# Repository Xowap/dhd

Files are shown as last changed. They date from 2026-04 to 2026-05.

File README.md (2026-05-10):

# DHD — Dial Hifi Device

<p align="center">
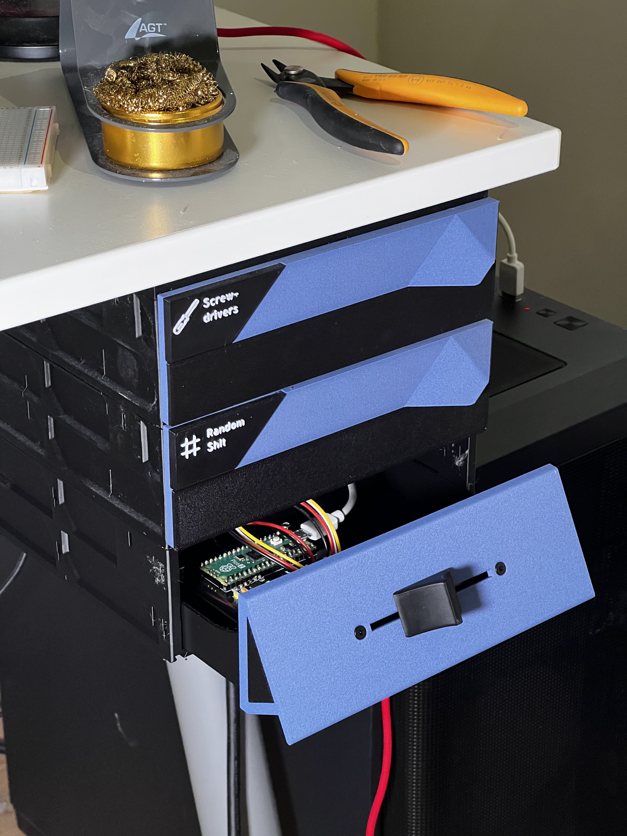
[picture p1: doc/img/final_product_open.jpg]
DHD — a physical motorized fader for computer volume control
  
</p>

<p align="center">
  <strong>A physical motorized fader for seamless computer volume control.</strong>
</p>

<p align="center">
  <a href="https://offworld-nexus-dhd.surge.sh">Documentation</a> ·
  <a href="https://offworld-nexus-dhd.surge.sh/assembly/">Assembly Guide</a> ·
  <a href="https://github.com/Xowap/dhd/tree/develop/hardware/stl">STL Files</a>
</p>

---

Move the fader by hand to adjust volume. Change volume from your computer and
watch the fader glide to match. Bidirectional, seamless, satisfying.

The DHD uses a **Bourns PSL60 motorized fader** with a PID-controlled DC motor,
driven by a **Raspberry Pi Pico 2** and a **DRV8833 motor driver**. The host
daemon on Linux integrates with PulseAudio/PipeWire for system volume control.

The enclosure is designed as a **GEN2 drawer** — it slides directly into the
[GEN2 modular system](https://www.jerrari3d.com/gen2-modular-system) with no
custom fixation needed.

## Features

- **Bidirectional control** — physical fader ↔ software volume, always in sync
- **Auto-calibration** — PID controller tunes itself to your hardware
- **GEN2 compatible** — standard drawer form factor, mounts in seconds
- **Plug and play** — USB auto-discovery, no configuration needed
- **Persistent** — calibration saved to flash, survives reboots

## Quick Start

See the full [documentation](https://offworld-nexus-dhd.surge.sh) for detailed
assembly and installation instructions.

```bash
# Clone
git clone https://github.com/Xowap/dhd.git
cd dhd

# Flash firmware (hold BOOTSEL while plugging in Pico)
rustup target add thumbv8m.main-none-eabihf
cd firmware && cargo run --release && cd ..

# Install host daemon
cd host && cargo run --release -- install && cd ..
```

## Project Structure

```
dhd/
├── common/      # Shared library — protocol + PID controller (no_std)
├── firmware/    # Embassy async firmware for RP2350
├── host/        # Linux host daemon (Tokio + PulseAudio + systray)
├── simulator/   # TUI PID simulator for tuning without hardware
├── hardware/
│   ├── kicad/   # PCB schematics
│   └── stl/     # 3D printable parts
└── doc/         # Documentation source (Zensical)
```

## Documentation

The full documentation is published at
**[offworld-nexus-dhd.surge.sh](https://offworld-nexus-dhd.surge.sh)** and
covers:

- Assembly instructions (BOM, PCB, 3D printing, step-by-step)
- Host software reference (installation, usage, protocol)
- Internals (PID control, motor driver, wiring)

## License

This project is open source. Hardware (KiCad + STL), firmware, and host software
are all available in this repository.

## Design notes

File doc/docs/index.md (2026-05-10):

---
title: Home
---

# DHD — Dial Hifi Device

<figure markdown>
  DHD Final Product
  <figcaption>The DHD installed in a GEN2 drawer, open view</figcaption>
</figure>

The **Dial Hifi Device** (DHD) is a physical motorized fader that provides
seamless bidirectional volume control for your computer. Move the fader by hand
to adjust volume, or change volume from your computer and watch the fader glide
to match — like a professional mixing console on your desk.

## Key Features

- **Bidirectional control** — adjust volume physically or from software, both
  stay in sync
- **Auto-calibration** — the PID controller automatically tunes itself to your
  specific hardware
- **GEN2 drawer compatible** — mounts directly into the
  [GEN2 modular system](https://www.jerrari3d.com/gen2-modular-system), no need
  to reinvent a fixation system
- **Fully open source** — hardware (KiCad + STL), firmware (Rust/Embassy), and
  host software (Rust/Tokio) are all available

## How It Works

The system uses a **Bourns PSL60 motorized fader** driven by a **DRV8833 motor
driver**, controlled by a **Raspberry Pi Pico 2** running an Embassy async
firmware. A PID controller with automatic calibration handles precise motor
positioning. The host daemon on Linux integrates with PulseAudio/PipeWire via a
JSON-over-USB protocol.

## Getting Started

Ready to build one? Head to the [Assembly Guide](assembly/index.md) to get
started.

Already assembled? Check the [Host Software](host/installation.md) section to
set up the Linux daemon.

## 3D Printed Parts

All parts are designed for the GEN2 modular drawer system:

<div class="grid cards" markdown>

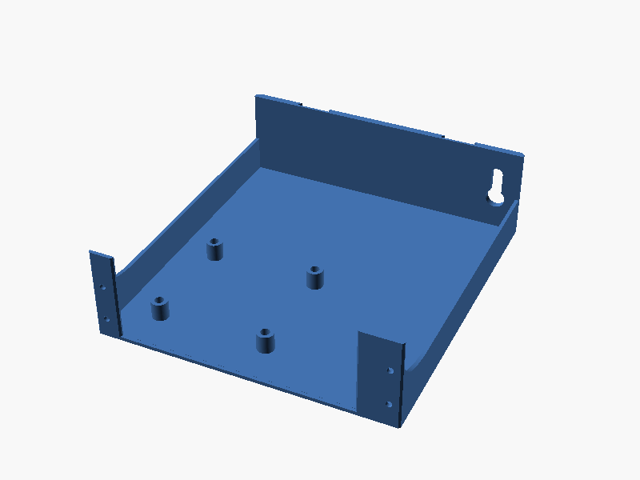
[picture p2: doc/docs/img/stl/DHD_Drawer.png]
Drawer
- 

    **Drawer**

    The base structure and GEN2 compatibility layer.

    [:octicons-download-16: Download STL](https://github.com/Xowap/dhd/raw/develop/hardware/stl/DHD_Drawer.stl)

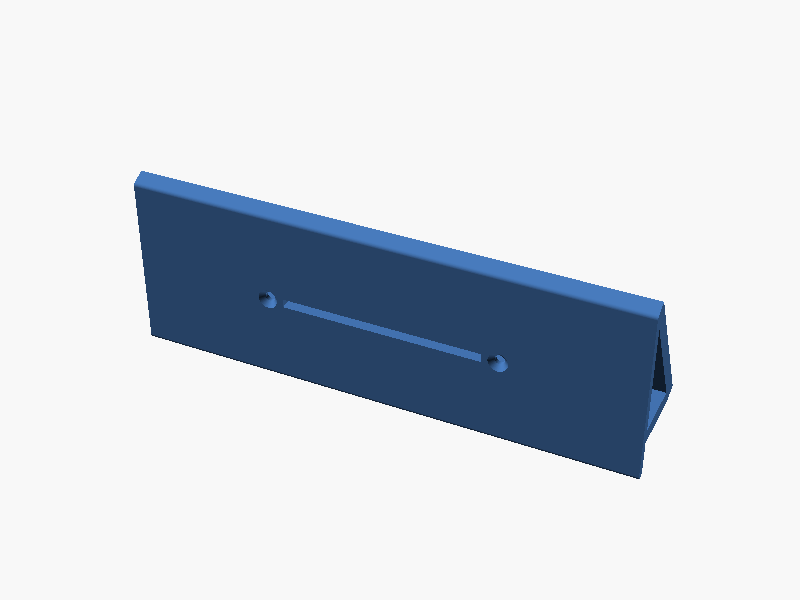
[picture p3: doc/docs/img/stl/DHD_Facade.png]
Facade
- 

    **Facade**

    The main component holding the fader.

    [:octicons-download-16: Download STL](https://github.com/Xowap/dhd/raw/develop/hardware/stl/DHD_Facade.stl)

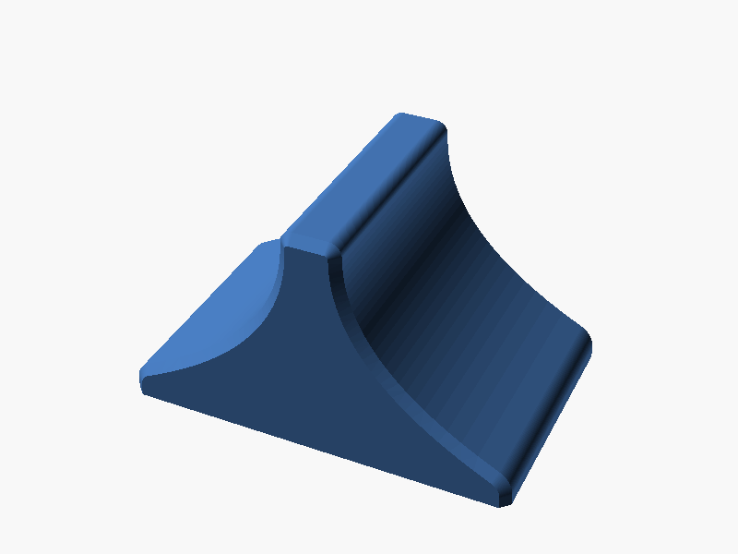
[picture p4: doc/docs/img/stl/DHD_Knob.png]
Knob
- 

    **Knob**

    Studio-style knob for comfortable control.

    [:octicons-download-16: Download STL](https://github.com/Xowap/dhd/raw/develop/hardware/stl/DHD_Knob.stl)

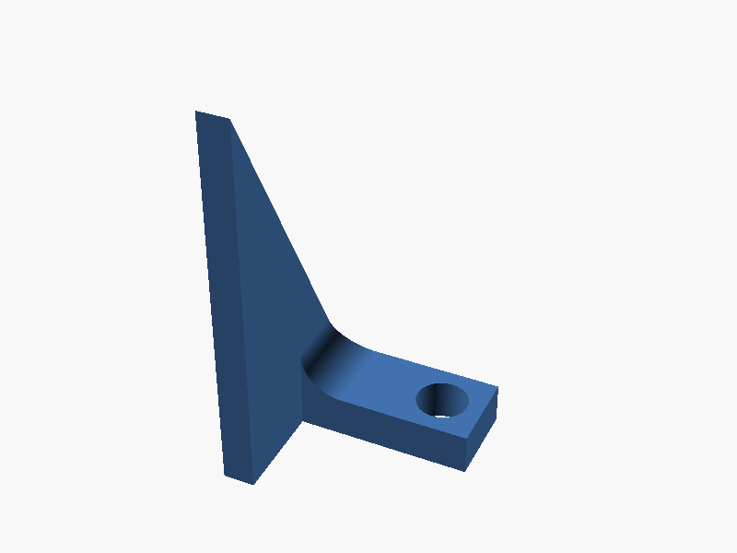
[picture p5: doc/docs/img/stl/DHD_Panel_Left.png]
Panel Left
- 

    **Side Panels**

    Cosmetic panels to close off the sides.

    [:octicons-download-16: Left](https://github.com/Xowap/dhd/raw/develop/hardware/stl/DHD_Panel_Left.stl) ·
    [:octicons-download-16: Right](https://github.com/Xowap/dhd/raw/develop/hardware/stl/DHD_Panel_Right.stl)

</div>

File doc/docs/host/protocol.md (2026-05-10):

# Protocol Reference

The DHD uses a JSON-based protocol over USB CDC-ACM (virtual serial port) for
communication between firmware and host. The message types are defined in
[`common/src/lib.rs`](https://github.com/Xowap/dhd/blob/develop/common/src/lib.rs).

## Transport

| Parameter | Value |
|---|---|
| Physical layer | USB 2.0 Full Speed |
| Device class | CDC-ACM |
| Baud rate | 115,200 (software-emulated) |
| Framing | Newline-delimited (`\n`) JSON objects |
| Packet size | 64 bytes (with ZLP flushing) |

---

## Messages — Host → Device

### `handshake` — Connection challenge

```json
{"handshake": {"message": "Tek'ma'te Teal'c"}}
```

| Field | Type | Description |
|---|---|---|
| `message` | string (max 32) | Challenge phrase |

Sent immediately on connection. Device must reply within 2 seconds.

### `ping` — Heartbeat

```json
{"ping": {"timestamp": 1715350000000}}
```

| Field | Type | Description |
|---|---|---|
| `timestamp` | u64 | Milliseconds since UNIX epoch |

Sent every 1 second. 3 missed pongs triggers reconnection.

### `start_calibration` — Trigger calibration

```json
{"start_calibration": {"volume": 0.5, "force": false}}
```

| Field | Type | Description |
|---|---|---|
| `volume` | f32 (0.0–1.0) | Target position after calibration |
| `force` | bool | `true` = full recalibration regardless of stored data |

### `set_volume` — Move fader to position

```json
{"set_volume": {"value": 0.75}}
```

| Field | Type | Description |
|---|---|---|
| `value` | f32 (0.0–1.0) | Target volume position |

Transitions device to `LogicallyDriven` mode.

### `update_calibration` — Manual ADC range override

```json
{"update_calibration": {"bottom": 120, "top": 3950}}
```

| Field | Type | Description |
|---|---|---|
| `bottom` | u16 | Minimum raw ADC value |
| `top` | u16 | Maximum raw ADC value |

Reserved for external/diagnostic use (not sent by the current host).

### `invert_scale` — Toggle scale direction

```json
{"invert_scale": null}
```

No fields. Toggles the mapping direction (0%↔100% swap).

---

## Messages — Device → Host

### `handshake` — Identity confirmation

```json
{"handshake": {"message": "Tek'ma'te Bra'tac"}}
```

| Field | Type | Description |
|---|---|---|
| `message` | string (max 32) | Response phrase |

### `pong` — Heartbeat response

```json
{"pong": {"timestamp": 1715350000000}}
```

| Field | Type | Description |
|---|---|---|
| `timestamp` | u64 | Echoed from the corresponding `ping` |

### `volume` — Fader position update

```json
{"volume": {"value": 0.42}}
```

| Field | Type | Description |
|---|---|---|
| `value` | f32 (0.0–1.0) | Current normalized fader position |

Only sent in `Standby` and `PhysicallyDriven` modes (prevents echo loops).

### `mode` — State change notification

```json
{"mode": {"mode": "Standby"}}
```

| Field | Type | Description |
|---|---|---|
| `mode` | string | One of the system modes (see below) |

**System modes:**

| Mode | Description |
|---|---|
| `Init` | Device booting, awaiting handshake |
| `Calibration` | Auto-calibration in progress |
| `Standby` | Idle, waiting for input |
| `PhysicallyDriven` | User is moving the fader by hand |
| `LogicallyDriven` | Motor is moving fader to a host-requested position |
| `Failsafe` | Communication error, motor disabled |

### `log` — Diagnostic message

```json
{"log": {"level": "INFO", "message": "Calibration complete"}}
```

| Field | Type | Description |
|---|---|---|
| `level` | string (max 16) | `ERROR`, `WARN`, `INFO`, `DEBUG`, or `TRACE` |
| `message` | string (max 384) | Human-readable diagnostic |

### `scale_inverted` — Inversion state report

```json
{"scale_inverted": {"inverted": true}}
```

| Field | Type | Description |
|---|---|---|
| `inverted` | bool | `true` = scale is flipped |

Sent during handshake (before the response) and after each inversion toggle.

---

## Communication Sequences

### Connection & Initialization

```mermaid
sequenceDiagram
    participant Host
    participant Device

    Host->>Device: handshake ("Tek'ma'te Teal'c")
    Device-->>Host: scale_inverted (current state)
    Device-->>Host: handshake ("Tek'ma'te Bra'tac")
    Note over Host,Device: Connection established

    Host->>Device: start_calibration (volume, force: false)
    alt Stored calibration exists
        Device-->>Host: log ("Calibration loaded from flash")
        Device-->>Host: mode ("Standby")
    else No stored calibration
        Device-->>Host: mode ("Calibration")
        Note over Device: Physical + PID calibration runs
        Device-->>Host: mode ("Standby")
    end
```

### Health Monitoring

```mermaid
sequenceDiagram
    participant Host
    participant Device

    loop Every 1 second
        Host->>Device: ping (timestamp)
        Device-->>Host: pong (same timestamp)
    end

    Note over Host: If 3 pings unanswered...
    Host->>Host: Declare connection dead
    Host->>Host: Reconnect
```

### Physical Volume Adjustment

```mermaid
sequenceDiagram
    participant User
    participant Device
    participant Host
    participant PulseAudio

    User->>Device: Moves fader by hand
    Device-->>Host: mode ("PhysicallyDriven")
    Device-->>Host: volume (0.42)
    Host->>PulseAudio: set_sink_volume(42%)
    Note over User: Volume audibly changes
    User->>Device: Releases fader
    Device-->>Host: mode ("Standby")
```

### External Volume Change (Software → Hardware)

```mermaid
sequenceDiagram
    participant App
    participant PulseAudio
    participant Host
    participant Device

    App->>PulseAudio: Set volume to 65%
    PulseAudio-->>Host: Volume change event
    Host->>Device: set_volume (0.65)
    Device-->>Host: mode ("LogicallyDriven")
    Note over Device: PID drives motor to position
    Device-->>Host: mode ("Standby")
```

### Forced Recalibration

```mermaid
sequenceDiagram
    participant User
    participant Host
    participant Device

    User->>Host: SIGUSR1 or systray "Force Calibration"
    Host->>Device: start_calibration (volume, force: true)
    Device-->>Host: mode ("Calibration")
    Note over Device: Full physical + PID recalibration
    Device-->>Host: mode ("Standby")
```

### Scale Inversion Toggle

```mermaid
sequenceDiagram
    participant User
    participant Host
    participant Device

    User->>Host: SIGUSR2 or systray "Invert Scale"
    Host->>Device: invert_scale
    Device->>Device: Toggle internal flag + save to flash
    Device-->>Host: scale_inverted (new state)
```

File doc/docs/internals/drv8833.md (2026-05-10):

# Motor Driver — DRV8833

The DRV8833 is a dual H-bridge motor driver used to control the motorized fader's
DC motor. Only one channel is used in this project.

## Key Specifications

| Parameter | Value |
|---|---|
| Logic voltage | 3.3V compatible |
| Motor voltage (VM) | 2.7–10.8V |
| Continuous current per channel | 1.5A |
| Peak current | 2A |
| Control mode | PWM (Slow Decay) |

## Pin Connections

| DRV8833 Pin | Connects To | Purpose |
|---|---|---|
| **VM** (VCC) | Pico VBUS (Pin 40, 5V) | Motor power supply |
| **GND** | Pico GND (Pin 38) | Common ground |
| **IN1** | GP14 (Pin 19) | PWM channel A (forward) |
| **IN2** | GP15 (Pin 20) | PWM channel B (reverse) |
| **OUT1** | Motor pin A | Power to motor |
| **OUT2** | Motor pin B | Power to motor |
| **EEP** (nSLEEP) | 3.3V (Pin 36) | Must be HIGH to enable driver |

## Control Truth Table

The firmware uses **Slow Decay** mode for precise PWM control:

| IN1 | IN2 | Function |
|-----|-----|---|
| PWM | LOW | Forward at PWM duty |
| LOW | PWM | Reverse at PWM duty |
| LOW | LOW | Coast (motor free-spins) |
| HIGH | HIGH | Brake (motor shorts) |

## Firmware Implementation

The firmware configures GP14 and GP15 as PWM outputs on **PWM Slice 7**
(`PWM7_A` and `PWM7_B`). The PID controller outputs are mapped to (see
[`firmware/src/fader/interface.rs`](https://github.com/Xowap/dhd/blob/develop/firmware/src/fader/interface.rs)):

- Positive effort → IN1 = duty, IN2 = HIGH (slow decay forward)
- Negative effort → IN1 = HIGH, IN2 = duty (slow decay reverse)
- Zero effort → both LOW (coast)

The slow decay mode (brake when OFF) provides better position holding and
smoother low-speed control compared to fast decay (coast when OFF).

## Unused Pins

The DRV8833 breakout has additional pins not used in this project:

- **IN3/IN4, OUT3/OUT4** — second H-bridge channel (unused)
- **nFAULT** — open-drain fault indicator (not monitored)
- **xISEN** — current sense resistor connection (tied to GND)

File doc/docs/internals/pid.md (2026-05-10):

# PID Control System

This document describes the design and implementation of the PID control system
used for the motorized fader.

## Problem Overview

A motorized fader is a **second-order mechanical plant** with significant
non-linearities caused by friction. The control goal is to drive the fader to a
target position (0.0 to 1.0) with:

- Zero steady-state error
- Minimal overshoot (solid, weighted feel)
- No high-frequency oscillation or chatter
- Robustness against ADC noise

## Physical Model

The fader is modeled using Newton's Second Law:

$$m \cdot \frac{d^2x}{dt^2} = F_{motor} - F_{friction}$$

### Friction Components

1. **Stiction** — minimum force to start movement (handled by `min_gain`)
2. **Kinetic friction** — constant opposing force during motion
3. **Viscous damping** — force proportional to velocity ($F = -b \cdot v$)

### System Gain

The calibration identifies two key parameters:

- **$k_v$** — terminal velocity per unit force above stiction
- **$\tau$** — mechanical time constant (time to reach 63% of terminal velocity)
- **$k_a = k_v / \tau$** — the acceleration constant

## Controller Architecture

Implemented in [`common/src/pid/controller.rs`](https://github.com/Xowap/dhd/blob/develop/common/src/pid/controller.rs) as a modified PD+I loop.

### Derivative-on-Measurement

Instead of differentiating the error (which causes setpoint kick), we use:

$$D = -K_d \cdot v_{estimated}$$

Velocity is estimated by applying a single-pole EMA filter to position, then
taking successive differences of the filtered signal. This rejects high-frequency
ADC noise while providing the damping needed to arrest momentum.

### Friction-Aware Output Mapping

The PID effort $u$ is mapped into the usable motor range:

$$Output = \text{sign}(u) \cdot \min(min\_gain + |u|,\ max\_gain)$$

When effort is near zero, the output defaults to $\text{sign}(error) \cdot min\_gain$
to prevent stalling in the stiction deadzone.

### Hysteretic Deadbanding

Two thresholds prevent motor hunting around the target:

1. **Engage band** (1.5× noise floor) — motor stays off until error exceeds this
2. **Disengage band** (1× noise floor + velocity ≈ 0) — motor stays active until
   both conditions are met

On re-engagement, the integral term is reset to zero to prevent accumulated
wind-up from causing a kick.

### Integral Anti-Windup

The integral only accumulates when the output is not saturated **in the same
direction as the error**. This allows the integral to decrease (error sign
flipped) even while output is at the rail, preventing overshoot from stored
error.

## Auto-Calibration

Implemented in [`common/src/pid/calibration.rs`](https://github.com/Xowap/dhd/blob/develop/common/src/pid/calibration.rs). Fully hardware-agnostic.

### Phase 1 — System Identification

A constant force is applied and the velocity response is observed:

1. Record position history over a step response
2. Compute velocities via central differences
3. Find **terminal velocity** ($v_{max}$)
4. Find **time constant** ($\tau$) — time to reach 63% of $v_{max}$
5. Compute $k_v = v_{max} / F_{applied}$ and $k_a = k_v / \tau$

### Phase 2 — Bandwidth Search

The entire PID loop is parameterized by a single variable: **closed-loop
bandwidth** ($\omega_n$).

For each candidate $\omega_n$, gains are computed via pole placement:

- $K_p = \omega_n^2 / k_a$
- $K_d = (2 \cdot \zeta_{target} \cdot \omega_n - 1/\tau) / k_a$
  (clamped ≥ 0)
- $K_i = 0.2 \cdot K_p \cdot \omega_n$
- Target damping: $\zeta = 1.4$ (significantly overdamped for stability)

A bidirectional step test scores each candidate:

$$Score = IAE \times 2 + OvershootPenalty + SettlePenalty + FinalErrorPenalty$$

Where:

- **Overshoot penalty:** $(overshoot - 0.02) \times 10000$ if > 2%
- **Settle penalty:** $settle\_sample \times 0.5$ if settled, else 500
- **Final error penalty:** $(final\_err - 0.02) \times 20000$ if > 2%

The algorithm runs a 6-step coarse grid followed by a 3-step fine refinement
around the best candidate.

## References

- [PID Controller (Wikipedia)](https://en.wikipedia.org/wiki/Proportional%E2%80%93integral%E2%80%93derivative_controller)
- [Integral Windup](https://en.wikipedia.org/wiki/Integral_windup)
- [Ziegler-Nichols & related methods](https://en.wikipedia.org/wiki/Ziegler%E2%80%93Nichols_method)

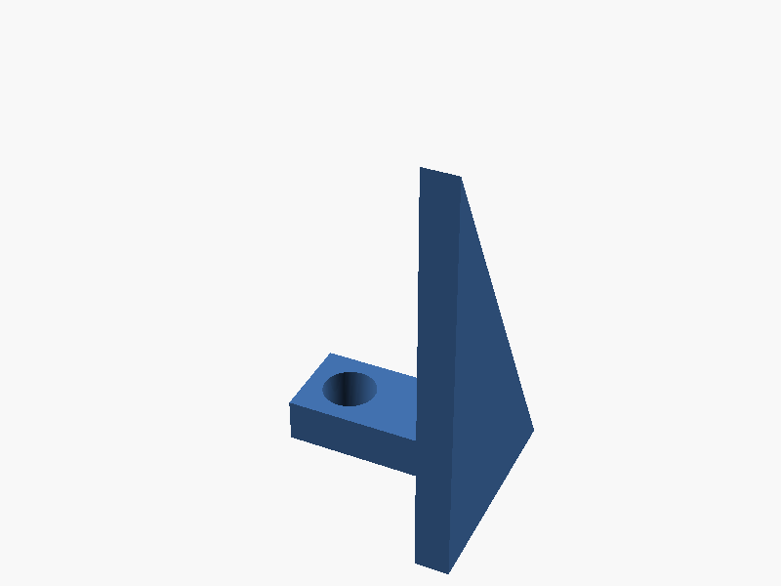
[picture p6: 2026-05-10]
doc/docs/img/stl/DHD_Panel_Right.png

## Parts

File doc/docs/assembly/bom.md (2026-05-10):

# Bill of Materials

These are the things that you need to get from stores:

| Item | Type | Qty  | What I Bought |
| --- | --- | ---- | --- |
| Bourns PSL60 | Motorized fader | 1 | [PSL60-1082A-103B1](https://es.farnell.com/bourns/psl60-1082a-103b1/pot-desliz-10k-20-0-5w-pasante/dp/2838883) |
| Raspberry Pi Pico 2 | Microcontroller | 1 | [ASIN: B0DCKH85WR](https://amzn.eu/d/0idjIjIz) |
| DRV8833 (on breakout board) | Circuit | 1 | [ASIN: B0DHRFRG6X](https://amzn.eu/d/0flBWfpK) |
| 2-Pin JST-XH Vertical Header (2.54mm) | Connector | 1 | [ASIN: B0BZHR5NCR](https://amzn.eu/d/08iP7cfn) |
| 2-Pin JST-XH Female Housing (2.54mm) | Connector | 1 | [ASIN: B0BZHR5NCR](https://amzn.eu/d/08iP7cfn) |
| 4-Pin JST-XH Vertical Header (2.54mm) | Connector | 1 | [ASIN: B0BZHR5NCR](https://amzn.eu/d/08iP7cfn) |
| 4-Pin JST-XH Female Housing (2.54mm) | Connector | 1 | [ASIN: B0BZHR5NCR](https://amzn.eu/d/08iP7cfn) |
| 4-Pin JST-PH Cables with Male Plug Connector (2.00mm) | Cable | 1 | [ASIN: B0C9C9VF4T](https://amzn.eu/d/00JlXiUl) |
| M3×6 hex socket head cap screw | Screw | 8 | [ASIN: B0DQ19XG23](https://amzn.eu/d/08OMiqco) |
| M3×8 hex socket countersunk head screw | Screw | 4 | [ASIN: B0DPWZ53X4](https://amzn.eu/d/03UlMjSr) |
| M3×4.0×5.0 heat-set insert | Heat-set insert | 2 | [ASIN: B0B2DMWFT2](https://amzn.eu/d/09NEdmbo) |
| M3×4.8×5.0 heat-set insert | Heat-set insert | 4 | [ASIN: B0B2DMWFT2](https://amzn.eu/d/09NEdmbo) |
| M3×5.7×5.0 heat-set insert | Heat-set insert | 4 | [ASIN: B0B2DMWFT2](https://amzn.eu/d/09NEdmbo) |

!!! note
    The "what I bought" links are not affiliated, and as a matter of fact most of them are not buyable anymore. But at least this way you can see exactly what I'm referring to.

## Operating Margin

Overall, I understand that you might not find where you are exactly what is listed above, depending on the country in which you are.

- **The fader** — As long as you have a fader with a 2-wired motor and the "1 2 3" pins, you should be good. We're not using the "T" pin, so you don't have to wire it in the connector if you don't have it. The software makes as few assumptions as possible, so any fader should be compatible. The design [in Onshape](https://cad.onshape.com/documents/e0a1011ad933c9838ad313ca/w/9072f4ad6800d0c6b8320443/e/6ad28f5df8e4bbfb02ddf18f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) is also configured to be easily modified to fit a differently-sized fader.
- **Raspberry Pi Pico 2** — This is tested on the Pico 2 (non-W) specifically. The Pico 1 has a different chip (RP2040 vs RP2350) so the firmware won't just flash as-is — you'd need to retarget it, which might range from trivial to annoying depending on what Embassy decides to do. The Pico 2 W should be closer to compatible since it's the same chip, but it's untested and who knows what the wireless hardware does to the USB stack or power delivery. Bottom line: if you use anything other than a plain Pico 2, you're in uncharted territory and some adaptation may be required.
- **DRV8833** — My understanding is that the breakout board is not standard for this component. So obviously you'll either have to find the same one or to re-wire the PCB.
- **JST connectors** — The PSL60 uses 2mm pins and the board 2.54mm pins. I'm counting on the cables to do the "translation" (see below). Change the size of the headers and you'll need to update the PCB a bit.
- **Screws** and **heat-set inserts** — Most places allow for longer screws or inserts without any major issue. Even a shorter insert is hardly ever going to be a problem, as the mechanical properties required for this assembly are very achievable. The main thing to be mindful of is to have sufficiently long screws, otherwise they risk not screwing anything. Also the screw heads (countersunk vs head cap) have their importance but then again it *would* hold even with the wrong head, if you're not afraid of ugly.

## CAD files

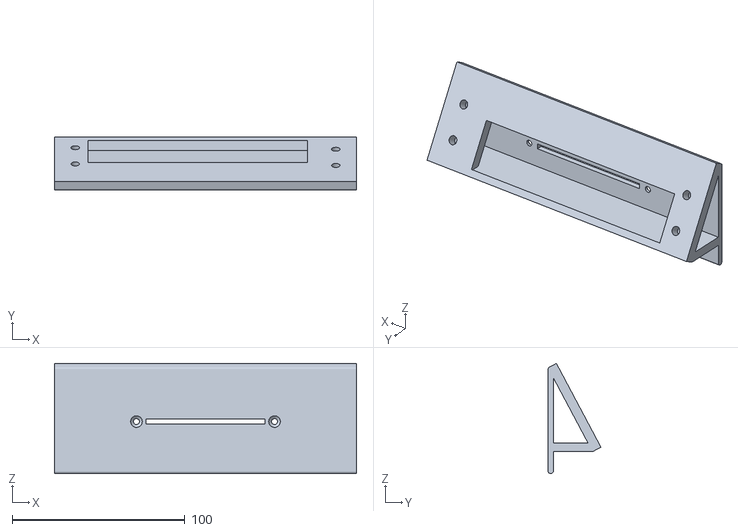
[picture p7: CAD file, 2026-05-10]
hardware/stl/DHD_Facade.stl
175.0 x 30.7 x 63.9

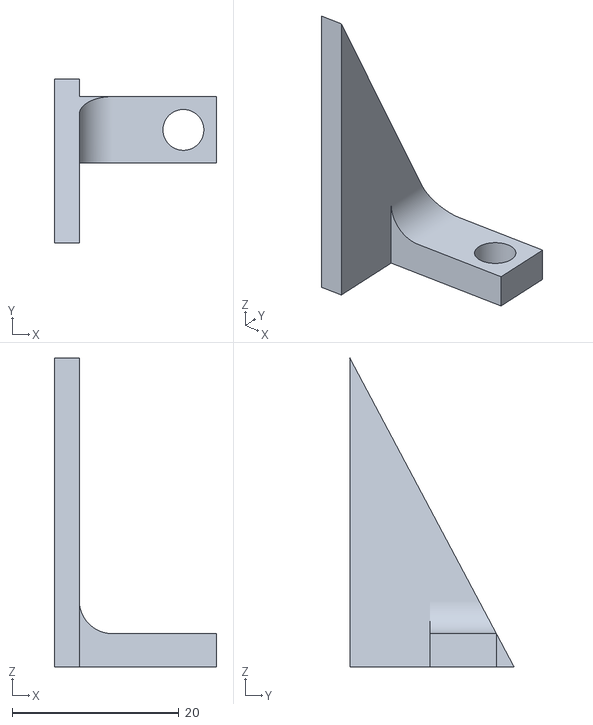
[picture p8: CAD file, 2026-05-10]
hardware/stl/DHD_Panel_Left.stl
19.5 x 19.7 x 37.1

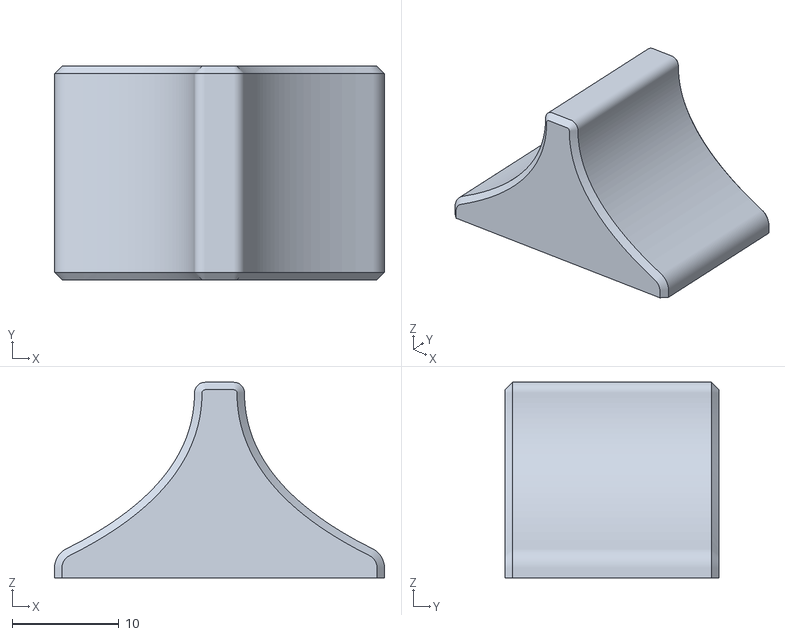
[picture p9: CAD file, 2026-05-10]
hardware/stl/DHD_Knob.stl
30.9 x 20.0 x 18.3

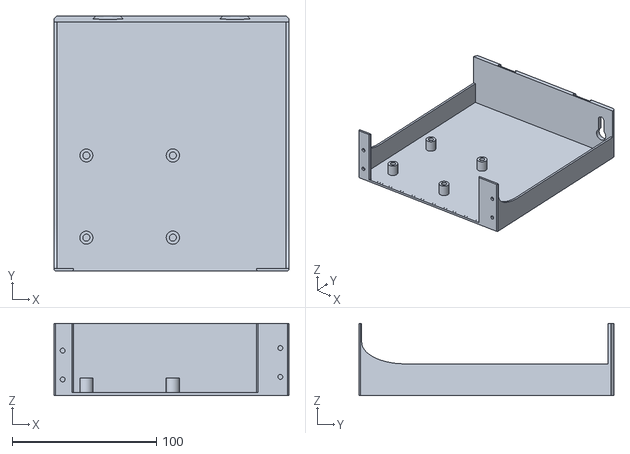
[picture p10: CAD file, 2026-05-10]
hardware/stl/DHD_Drawer.stl
163.0 x 176.9 x 50.0

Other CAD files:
hardware/stl/DHD_Panel_Right.stl

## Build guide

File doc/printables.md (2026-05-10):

# DHD — Dial Hifi Device

A physical motorized fader that provides seamless bidirectional volume control for your computer.

Move the fader by hand to adjust volume. Change volume from your computer and watch the fader glide to match. Bidirectional, seamless, satisfying.

## What Is This?

The DHD uses a Bourns PSL60 motorized fader with a PID-controlled DC motor, driven by a Raspberry Pi Pico 2 and a DRV8833 motor driver. The host daemon on Linux integrates with PulseAudio/PipeWire for system volume control.

The enclosure is designed as a **GEN2 drawer** — it slides directly into the [GEN2 modular system](https://www.jerrari3d.com/gen2-modular-system) with no custom fixation needed.

**Drawer specs:** 185 depth, 2W×1H

## Features

- Bidirectional control — physical fader and software volume always stay in sync
- Auto-calibration — the PID controller tunes itself to your hardware
- GEN2 compatible — standard drawer form factor
- Plug and play — USB auto-discovery, no configuration

## What You Need

- Bourns PSL60 motorized fader
- Raspberry Pi Pico 2
- DRV8833 motor driver (breakout board)
- JST-XH connectors and cables
- M3 screws and heat-set inserts
- A GEN2 rail and 185-2W-1H case

## Documentation

**Full build guide, BOM, and software installation instructions:**

👉 **https://offworld-nexus-dhd.surge.sh**

The documentation covers everything from sourcing parts to flashing firmware.

## Source Code

Everything is open source — hardware (KiCad + STL), firmware (Rust/Embassy), and host software (Rust/Tokio):

👉 **https://github.com/Xowap/dhd**

## GEN2 Dependencies

You will also need to print:

- [GEN2-QL Rail — Double](https://www.printables.com/model/1052357-gen2-rails-185-standard/files)
- [185-2W-1H Case](https://www.printables.com/model/1658700-gen2-185-cases-all/files) (make sure it's the April 2026 or later version with the back wall hole)

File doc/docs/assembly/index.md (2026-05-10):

# Construction Guide

The Dial Hifi Device (DHD) is a DIY device which allows you to control the volume on your computer through a physical fader, which is mounted as the facade of a drawer for the GEN2 system. Obviously it's built with the parts that *I* have at hands, and building it for your own constraints might require to modify some things. Overall everything is open sourced: you have access to the [Onshape document](https://cad.onshape.com/documents/e0a1011ad933c9838ad313ca/w/9072f4ad6800d0c6b8320443/e/6ad28f5df8e4bbfb02ddf18f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), the [KiCad schematics](https://github.com/Xowap/dhd/tree/develop/hardware/kicad) and the [Rust source code](https://github.com/Xowap/dhd) for the computer program.

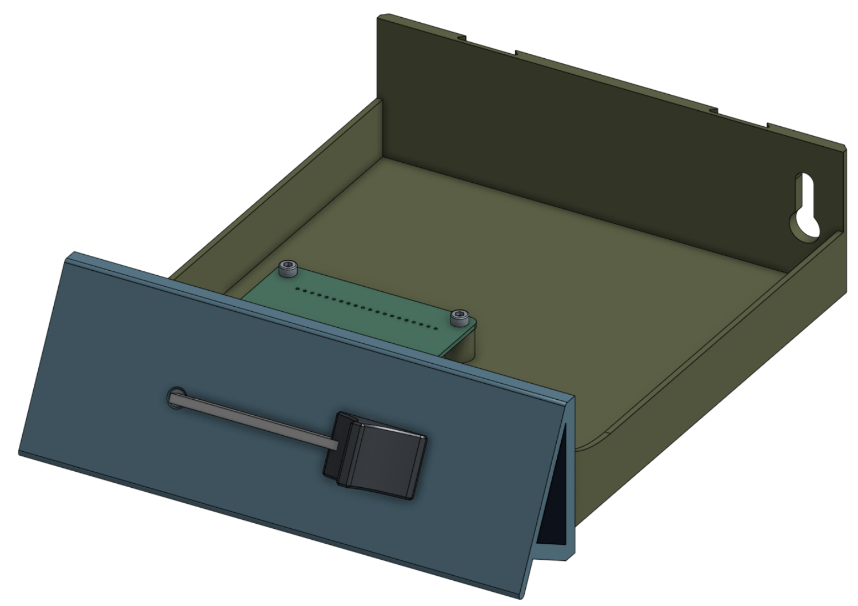
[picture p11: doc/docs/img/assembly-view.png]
Assembly overview


## Prerequisites

In order to build this device, you will need at least some experience with 3D printing and soldering, even though I'm trying to make this as easy as possible.

### Tools

These are the tools that you will need in order to assemble the product from start to finish (let me know if I forgot something):

- Required
    - **Soldering Iron** — Used both for soldering and for heat-set inserts insertion
    - **3D Printer** — In order to print the printable parts
- Recommended
    - **Hex screwdrivers/keys** — Probably sizes 2 and/or 2.5. You can always screw using your fingers only but that's definitely not the easiest way to go.
    - **Crimping tool** — To work with the JST connectors, you will need a crimping tool. You can always work with regular pliers and cry a lot if you don't have one.
    - **Automatic Wire Stripper** — Same as above. Those wires are tiny. But if you're good with a blade...

### Commodities

You will also need to consume a few things to get going:

- **Some filament** for your 3D printer (colors up to you, any PLA is fine)
- **Flux** and **wick** for soldering
- **2.54mm PCB Pin Header** to solder the Raspberry Pi and the driver, unless they already have some in the box

## What's Next

The construction is broken into the following steps:

1. **[Bill of Materials](bom.md)** — What to buy
2. **[PCB & Soldering](pcb.md)** — Building and soldering the electronics
3. **[3D Printing](printing.md)** — Printing the enclosure parts
4. **[Physical Assembly](steps.md)** — Putting it all together
5. **[GEN2 Integration](gen2.md)** — Mounting it in a GEN2 drawer system

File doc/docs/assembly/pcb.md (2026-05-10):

# PCB & Soldering

My understanding is that there are many ways to do this, however here is how I did it.

Within the source code, under the [`hardware/kicad`](https://github.com/Xowap/dhd/tree/develop/hardware/kicad) folder, you can find the schematics for the PCB, to be opened in the free software [KiCad](https://www.kicad.org/).

## Building the Board

!!! warning "Read first"
    Before building the board, read the instructions of the "2-pins header — The motor" below, because it might impact your process.

Then, up to you. If you know how to do this chemically or with a laser or whatever the cool kids do, knock yourself out. In my case, I decided to order it from PCBWay, because it's much easier. Here are the steps that I followed:

1. Open the PCB in KiCad (the project is in [`hardware/kicad/`](https://github.com/Xowap/dhd/tree/develop/hardware/kicad))

2. Export Gerber files:

    - Go to **File → Fabrication Outputs → Gerbers (.gbr)...**
    - Output directory: `gerbers/` (or any folder you like)
    - Make sure all layers are checked (F.Cu, B.Cu, F.Mask, B.Mask, F.Silkscreen, B.Silkscreen, Edge.Cuts, F.Paste, B.Paste)
    - Click **Plot**

3. Export drill files:

    - Still in the Gerber dialog, click **Generate Drill Files...**
    - Format: **Excellon**
    - Drill origin: **Absolute**
    - Click **Generate Drill File**

4. Put all those files (`.gbr` + `.drl`) at the root of a `.zip`

5. Go to PCBWay and use the [PCB Quick Order](https://www.pcbway.com/QuickOrderOnline.aspx) feature, which allows to directly upload this zip file and will deduce key parameters from it automatically (instead of having to fill them up manually, which is subtly different from the default form you'll get from the menu)

6. The defaults are good, but up to you to change anything you'd like, notably:

    1. Get **HASL lead free** for the **Surface finish**
    2. Pick a **Solder mask** with the color that you like

7. Follow with the order process

    !!! tip "Shipping"
        If you are wondering which carrier option you should take, pick one that offers **DDP**. It means that taxes will be paid in advance and will go through a pre-cleared channel at customs. It looks more expensive now, but your package will not stay stuck at border control for two weeks *and* you won't have to pay duty control fees on top of taxes *and* the tax collection won't be a bloody email circus with Fedex. So essentially it's not only cheaper but also faster and more predictable.

8. Wait a couple of days, and that's it the PCB is in your mail box

## Soldering Stuff

Now the soldering. It should be pretty straightforward. There are four items to solder:

- **Raspberry Pi Pico 2** — Goes into the long rail of holes, the USB port on the same side as the arrow saying "USB this way".
- **DRV8833** — It has a tiny white (when off) LED in the center of one of the edges of the board. There is a "LED" inscription pointing in the direction in which the edge containing this LED should be.
- **2-Pin JST-XH Vertical Header** — It should overlay nicely with the printed shapes on the board. The direction matters, but it should be fairly obvious.
- **4-Pin JST-XH Vertical Header** — Same as the 2-Pin friend.

## Connecting the Fader

So the fader needs two groups of cables. One for the potentiometer (the 4 pins) and one for the motor (the 2 pins). Let's see what/how to wire them.

### 4-pins header — The potentiometer

To connect the potentiometer, you need to build up a custom cable which is on each side:

- 4-Pin JST-XH Female Housing (2.54mm)
- 4-Pin JST-PH Female Housing (2.00mm)

The fader should have a label which says "1 2 T 3", which corresponds to the mapping of the wires next to it. The pins on the board are in the same order.

### 2-pins header — The motor

Okay there I did something stupid. The motor comes with PH connectors (2mm) and I put on the board XH connectors (2.54mm). The reason is that I wanted to use standard distances, but I didn't realize that there was no easy way to adapt this into that.

Things you can do:

- An easy solution is just to cut off the connector from existing cables, and then replace the connector with a XH one.
- Fix the PCB (if you didn't build it yet). I could have done that before publishing the project, but I don't want to publish some untested design so I prefer to keep the mistake and give you the reader options.
- Get an extra breakout board and adapt one onto the other cleanly

The good news however is that the polarity of the motor does not matter, so you can wire this in any combination you want.

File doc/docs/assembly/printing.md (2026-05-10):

# 3D Printing

The PCB is of course going to be a bit naked for regular use, which is why I also created a bunch of parts.

My desk is equipped with a couple of [GEN2](https://www.jerrari3d.com/gen2-modular-system) drawers (and associated rails), which is a fantastic drawer system might I add, and thus is perfect to attach this kind of projects as well. Which brought me to the conclusion: let's make a GEN2-drawer-shaped controller, this way I can stick it in a standard case and benefit from having the system already in place. The side effect of this decision is that you are going to need a GEN2 drawer rail and case in place to be able to mount the project, but more on that later.

!!! note
    In case you need to change anything about the 3D models, you can always clone the [Onshape document](https://cad.onshape.com/documents/e0a1011ad933c9838ad313ca/w/9072f4ad6800d0c6b8320443/e/6ad28f5df8e4bbfb02ddf18f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) to customize anything you would like. I've tried to make it understandable, and to have one single place to change any detail and get it rippling everywhere else automatically. For example if you modify the fader's ghost, it should automatically re-locate the holes and so forth on the facade.

## Parts

We have there to print the following parts:

| Part | Preview | STL | Purpose |
|---|---|-----|---|
| **Drawer** |  | [:octicons-download-16: Download](https://github.com/Xowap/dhd/raw/develop/hardware/stl/DHD_Drawer.stl) | The support structure for everything on top of being the compatibility layer with GEN2 |
| **Facade** |  | [:octicons-download-16: Download](https://github.com/Xowap/dhd/raw/develop/hardware/stl/DHD_Facade.stl) | The main component, and for which you could create a different support system if you don't like GEN2 (all you need is 4 holes and somewhere to put the PCB) |
| **Side Panels** |  | [:octicons-download-16: Left](https://github.com/Xowap/dhd/raw/develop/hardware/stl/DHD_Panel_Left.stl) · [:octicons-download-16: Right](https://github.com/Xowap/dhd/raw/develop/hardware/stl/DHD_Panel_Right.stl) | Only here for cosmetic reasons and close up the sides of the facade. Albeit technically optional, I don't really see the point of not printing them |
| **Knob** |  | [:octicons-download-16: Download](https://github.com/Xowap/dhd/raw/develop/hardware/stl/DHD_Knob.stl) | You put it on the sliding part of the fader, and gives you a studio feel (or at least is more comfortable to use than a rectangular piece of metal) |

## Color Strategy

- The drawer is cased away during normal use, so print it with anything you'd like but essentially you'll never actually see it
- The facade is obviously the main thing that you are going to be seeing, so print with a material that you like. Also take into account that there are two pretty prominent countersunk screws on it, so you might want to match up the color of the drawer and the color of the screws
- The side panels are going to be visible on the side, so I guess you can give them an accent color which goes well with the facade

## Printing Strategy

Everything prints without supports, although you might want to take this into consideration:

- **The drawer** prints flat without any surprises, although to be extra safe you might want a brim or at least some mouse ears
- **The facade** is relatively simple to print but you might want to decide which face to print it on:
    - My recommendation is to print it on one of the sides, as the only complication is a reasonable bridge which prints a bit soggy but stays hidden. So essentially, printing on the side is foolproof.
    - On the other hand, you might want fancy surface finish on the front face. In which case there is no major reason not to print it on the front face, except for the looong bridge it will create. But then again, it's on the back side and you won't ever see it, and there is ample margin around the fader.
- **The side panels** can be printed either:
    - On the outer face, which is by far the simplest. Depends the finish you want, but I'd go for that.
    - You can however also print it on the "support" (the bit with the screw hole), but the contact surface is pretty tiny and the shape prone to warping so you're gonna have to be careful about adhesion. Not sure why you would do that.
- **The knob** has to be printed on its back face, for better control over the tolerances inside (otherwise it's going to be bridging), which are honestly tight (on purpose, you don't want it to fall off do you?). Which sucks in terms of layer lines orientation, but is simpler. If you want to try it otherwise let me know how it goes.

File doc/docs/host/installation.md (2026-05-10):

# Installation

For now the software distribution is not fantastic, in the sense that you will also have to build it yourself.

First of all, it only works for Linux. So for other operating systems, you can probably vibe-code it pretty easily given that most of the code is portable, however yeah that's on you.

## Prerequisites

The things you'll need to get started are:

- `git`, of course
- and `rust`, so for example you can get [`rustup`](https://rustup.rs/)

## Getting the Code

Start by cloning the repo:

```bash
git clone https://github.com/Xowap/dhd.git
cd dhd
```

Then install the toolchain for cross-compilation (needed for the [`firmware/`](https://github.com/Xowap/dhd/tree/develop/firmware)):

```bash
rustup target add thumbv8m.main-none-eabihf
```

Then there are two components:

- The `firmware`, which runs on the device
- And the `host`, which runs on your computer and that is the Linux-only part

## Flashing the Firmware

So now, let's flash this firmware.

Look at your Raspberry Pi Pico 2. It has a `BOOTSEL` button. Maintain it pressed while plugging it to the USB port of your computer. This puts the device in "flashable" mode.

Subsequently, build and flash the firmware:

```bash
cd firmware
cargo run --release
cd ..
```

This will transfer the firmware to the device and then it should immediately turn on. Of course it does nothing on its own so you need to start the host software.

## Installing the Host

The host works in CLI mode, however if you intend on using it I recommend using the self-installer.

```bash
cd host
cargo run --release -- install
```

Doing so will:

- Install the binary in `~/.local/bin/dhd`
- Configure the application to appear in your menu and to start automatically at system launch

The installed files are listed, so if you want to cleanup afterwards it's very simple to do because you just need to delete them.

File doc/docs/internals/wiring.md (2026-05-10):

# Wiring Reference

This document describes the physical connections between the Raspberry Pi Pico 2
(RP2350) and the hardware components, as defined in the KiCad schematic
([`hardware/kicad/dhd.kicad_sch`](https://github.com/Xowap/dhd/blob/develop/hardware/kicad/dhd.kicad_sch)).

## Potentiometer (J2 — 4-pin JST-XH)

The Bourns PSL60 fader has 4 pins labeled "1 2 T 3" on the component.

| Fader Pin | Connector Pin | Pico Connection | Function |
|---|---|---|---|
| 1 | J2-1 | GP26 / ADC0 (Pin 31) | Wiper — analog position signal |
| 2 | J2-2 | — | Touch sense (unused, not connected) |
| T | — | — | (label on fader, not a separate pin) |
| 3 | J2-3 | AGND (Pin 33) | Ground reference (analog) |
| — | J2-4 | 3.3V (Pin 36) | Positive voltage reference |

!!! note "Analog ground"
    The schematic connects the pot ground to **AGND** (Pin 33) rather than a
    generic GND pin. This is best practice for clean ADC readings — it avoids
    noise coupling from digital circuits.

## Motor Driver (DRV8833 — dual 6-pin headers)

The DRV8833 breakout board is represented as two 6-pin connectors in the
schematic (left and right pin rows).

| DRV8833 Pin | Pico Connection | Purpose |
|---|---|---|
| VM / VCC | VBUS (Pin 40, 5V) | Motor power from USB |
| GND | GND (Pin 38) | Common ground |
| IN1 | GP14 (Pin 19) | PWM forward control |
| IN2 | GP15 (Pin 20) | PWM reverse control |
| EEP / nSLEEP | 3.3V (Pin 36) | Enable (must be HIGH) |
| OUT1 | J1-2 (Motor pin) | Motor power output |
| OUT2 | J1-1 (Motor pin) | Motor power output |

**Unused DRV8833 pins:** IN3, IN4, OUT3, OUT4 (second channel), ULT/nFAULT.

## Motor (J1 — 2-pin JST-XH)

| Pin | Connection | Note |
|-----|---|---|
| J1-1 | DRV8833 OUT2 | Polarity doesn't matter |
| J1-2 | DRV8833 OUT1 | Polarity doesn't matter |

## USB Connection

The Pico's USB port provides:

1. **Power** — 5V via VBUS to the motor driver, 3.3V regulated for logic
2. **Data** — CDC-ACM serial for the JSON protocol
3. **Flashing** — via BOOTSEL mode for firmware updates

## Firmware Pin Configuration

Confirmed in [`firmware/src/main.rs`](https://github.com/Xowap/dhd/blob/develop/firmware/src/main.rs):

```rust
// PWM motor control on Slice 7
let pwm = Pwm::new_output_ab(p.PWM_SLICE7, p.PIN_14, p.PIN_15, pwm_c);

// ADC input
let channel = Channel::new_pin(p.PIN_26, embassy_rp::gpio::Pull::None);
```

## Schematic Overview

```
                    ┌─────────────────────┐
                    │ Raspberry Pi Pico 2 │
                    │                     │
     3.3V (Pin 36) ─┤─── EEP (DRV8833)    │
                    │                     │
     VBUS (Pin 40) ─┤─── VM  (DRV8833)    │
                    │                     │
     GND (Pin 38) ──┤─── GND (DRV8833)    │
                    │                     │
    GP14 (Pin 19) ──┤─── IN1 (DRV8833)    │──── OUT1 ──┐
                    │                     │            │ Motor
    GP15 (Pin 20) ──┤─── IN2 (DRV8833)    │──── OUT2 ──┘
                    │                     │
    GP26 (Pin 31) ──┤─── Wiper (Pot)      │
                    │                     │
    AGND (Pin 33) ──┤─── GND   (Pot)      │
                    │                     │
     3.3V (Pin 36) ─┤─── VCC   (Pot)      │
                    │                     │
          USB ──────┤ Power + CDC-ACM     │
                    └─────────────────────┘
```

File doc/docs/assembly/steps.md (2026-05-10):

# Physical Assembly

Now is the time to assemble all that you have gathered and built.

## The BOM

Okay so to start, what should you have on your table? This list is different from the one above, as some elements already have been assembled and others have been printed.

| Item | Type | Qty  |
| --- | --- | ---- |
| Bourns PSL60 | Motorized fader | 1 |
| 4-Pin JST-PH to JST-XH cable | Cable | 1 |
| M3×6 hex socket head cap screw | Screw | 8 |
| M3×8 hex socket countersunk head screw | Screw | 4 |
| M3×4.0×5.0 heat-set insert | Heat-set insert | 2 |
| M3×4.8×5.0 heat-set insert | Heat-set insert | 4 |
| M3×5.7×5.0 heat-set insert | Heat-set insert | 4 |
| Drawer | Printed part | 1 |
| Facade | Printed part | 1 |
| Left panel | Printed part | 1 |
| Right panel | Printed part | 1 |
| Knob | Printed part | 1 |
| Soldered PCB | PCB | 1 |

## Phase A — Heat-set inserts

Grab your soldering iron, set it to about 50°C above printing temperature (so something like 270°C for PLA) and push the inserts into the plastic. This design is rather tolerant for different sizes of inserts, longer or shorter. Just make sure that the contact surface is flush so that the parts can be fastened closely.

### Step 1 — Insert into the panels

Push the M3×4.0×5.0 inserts into the panel's bottom holes. It can overflow in direction of the pointy end, but the bottom surface must be flush.

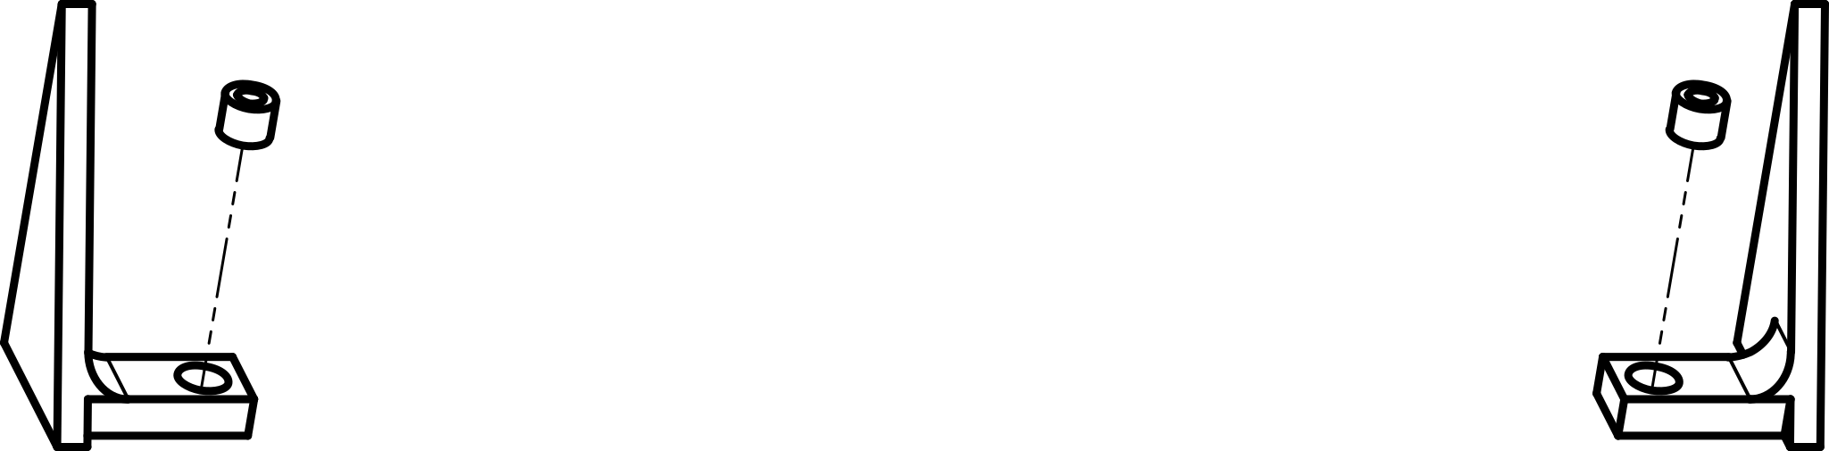
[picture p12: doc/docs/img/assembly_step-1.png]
Step 1


### Step 2 — Insert into the facade

Push the M3×4.8×5.0 inserts into the facade's back face. It can overflow inside of the facade, but the back face must be flush.

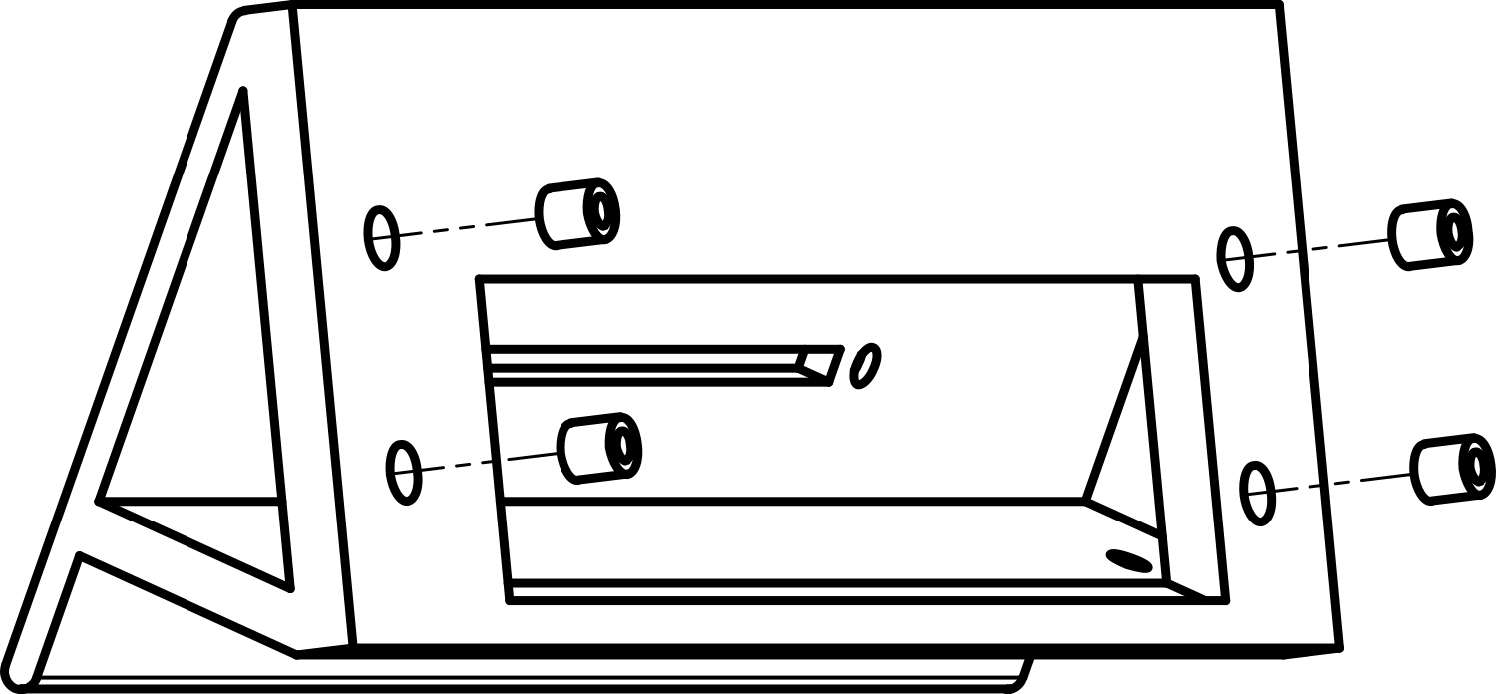
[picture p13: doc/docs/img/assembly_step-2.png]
Step 2


### Step 3 — Insert into the PCB support

Push the M3×5.7×5.0 inserts into the drawer's PCB support elements. If the surface isn't flush after insertion, it's not too dramatic as the PCB will be screwed in there.

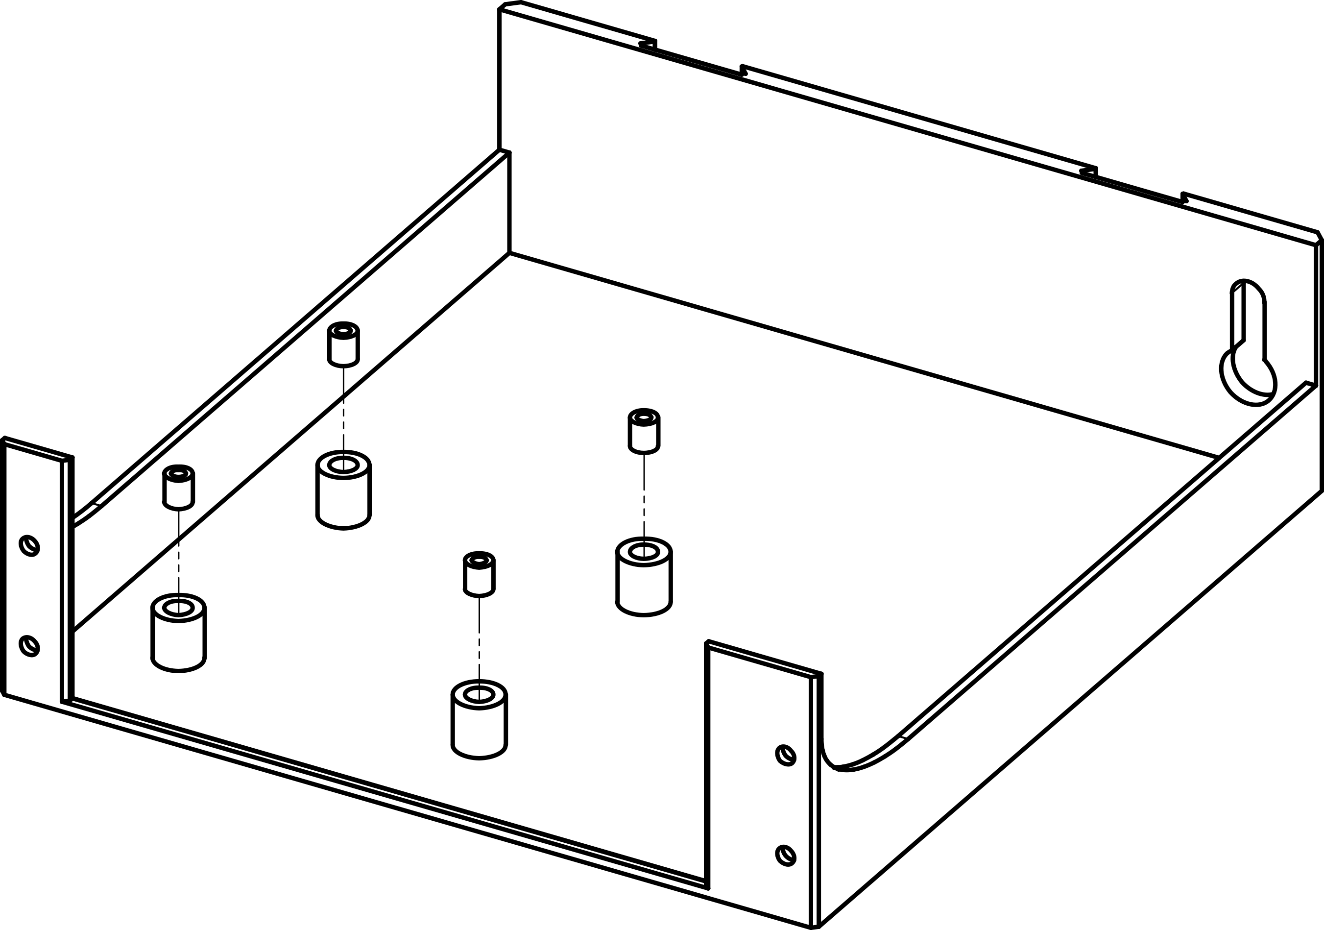
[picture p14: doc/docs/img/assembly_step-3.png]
Step 3


## Phase B — Facade assembly

The facade is the main part of this project, and almost works as an independent module. Here we assemble its components. The next phase will essentially only be to screw it to the drawer.

### Step 4 — Screw the panels

Position the panels more or less by pushing them from the side, then when their hole is sufficiently aligned with the screw hole from below, screw them with 2 M3×8 hex socket countersunk head screws.

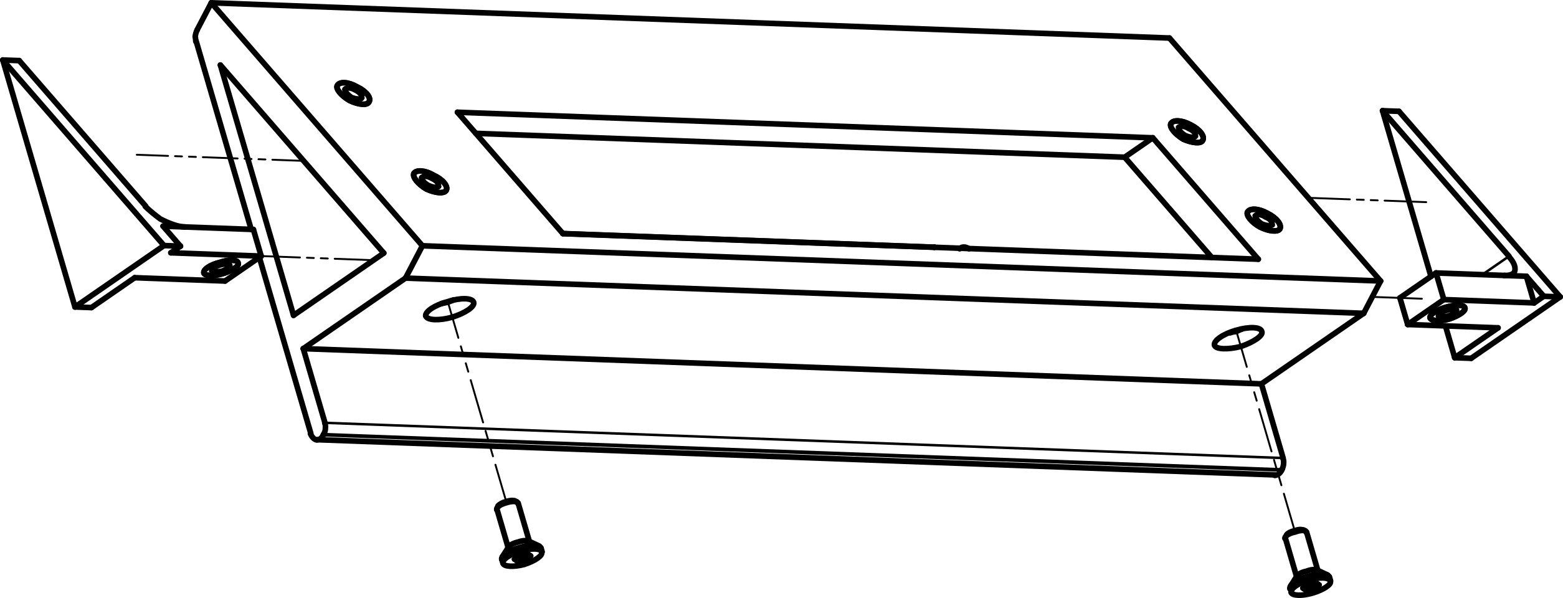
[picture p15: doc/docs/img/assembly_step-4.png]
Step 4


### Step 5 — Screw the fader

Here is represented the fader's "hitbox", which is slightly different from the actual fader, but I wasn't going to make a CAD model of it. Anyways, as you can see the socket for the potentiometer sensors is pointing up and the motor is on the left side if you look from the front. Use the other two M3×8 hex socket countersunk head screws.

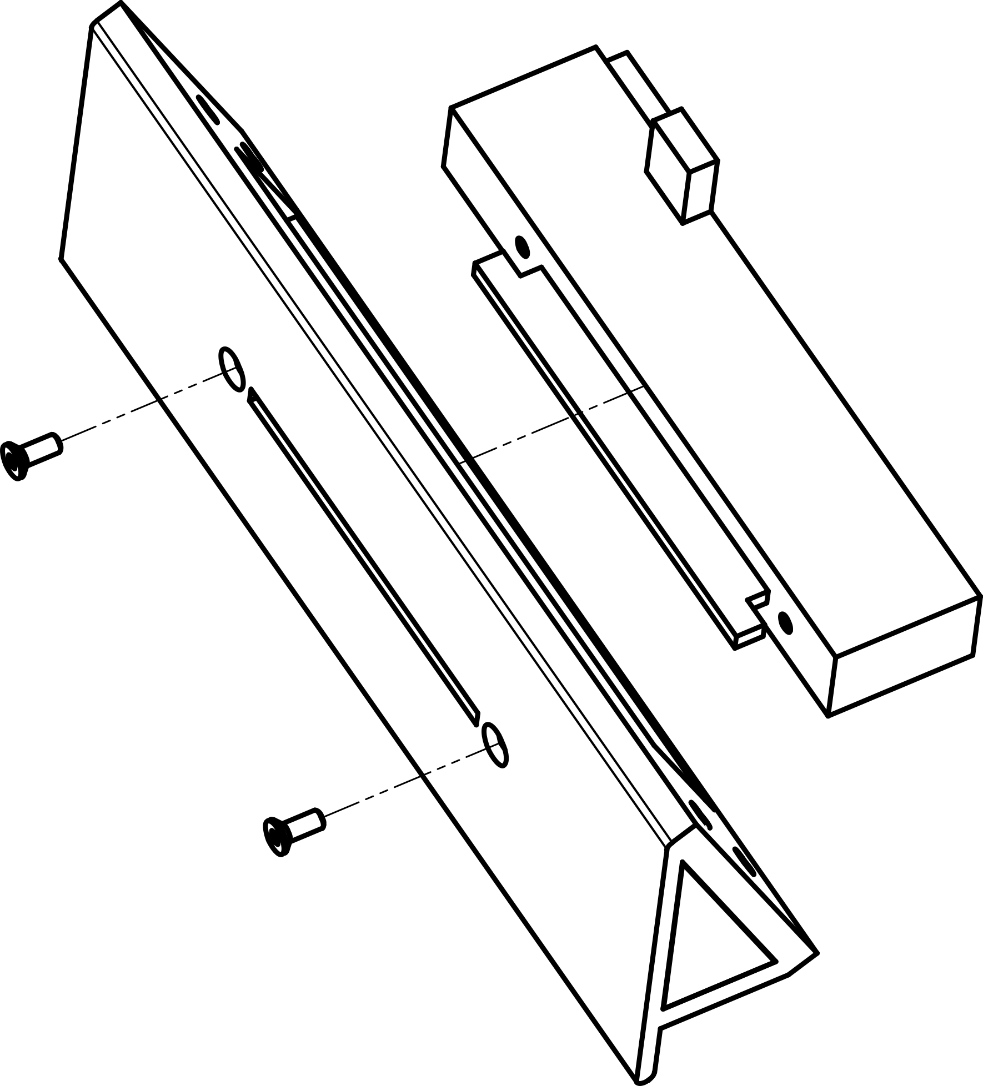
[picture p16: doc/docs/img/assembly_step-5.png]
Step 5


### Step 6 — Attach the knob

The knob just needs to be pushed into the fader's metal slider. If you observe the metal thing close enough, you will see that two circles are pressed on each side. Inside the knob's hole you should find the negative of these shapes. Take care to insert the knob in the right direction so that the relief on one side inserts itself in the hole inside the knob. Adjustments are very tight, so you may have to use a bit of force, although nothing too dramatic. It does not exactly click, but you might feel something when it gets into position. The knob should sit about 1mm from the front face.

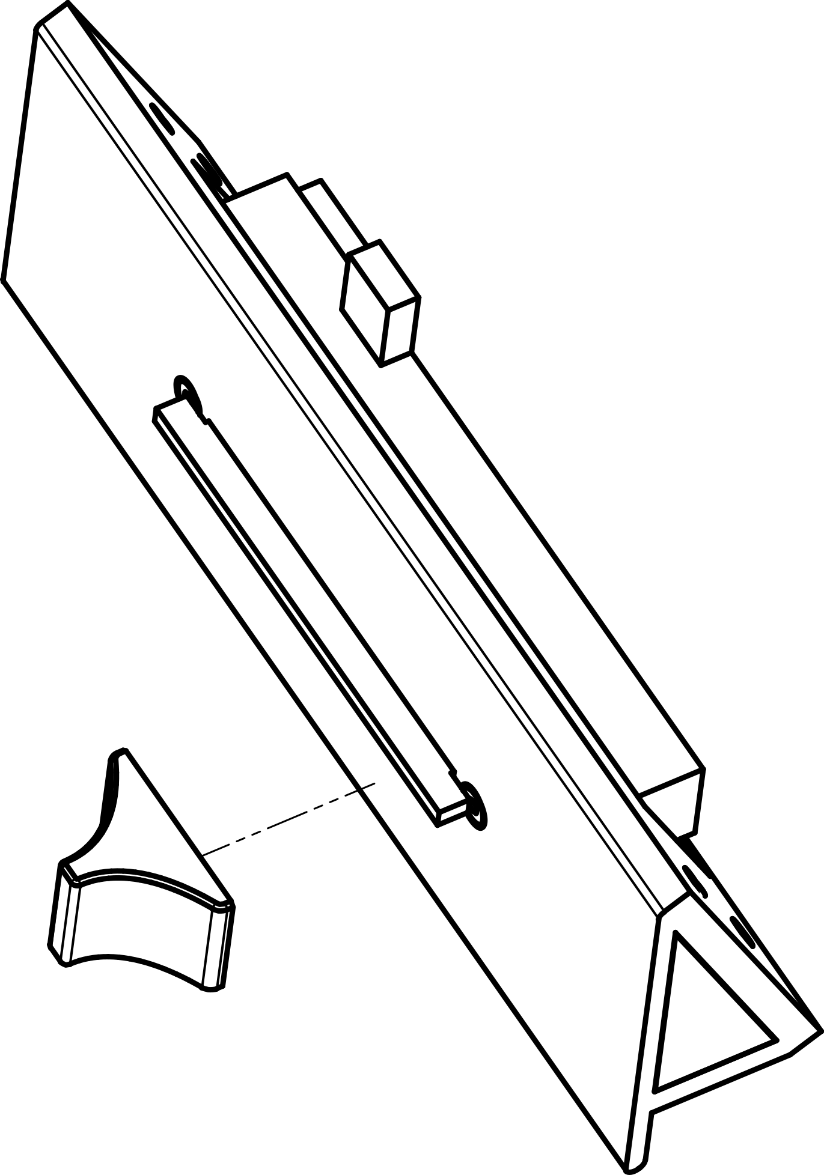
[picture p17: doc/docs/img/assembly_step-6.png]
Step 6


## Phase C — Bring it together

Now it's a simple question of connecting it all together.

### Step 7 — Screw the PCB

Be careful about the orientation of the PCB. Basically the Raspberry Pi's USB should point towards the right side, which is the side on which there is lots of space for the cable to hang. In doubt, look at the holes from the schema and line them up with what you have. Use 4 M3×6 hex socket head cap screws.

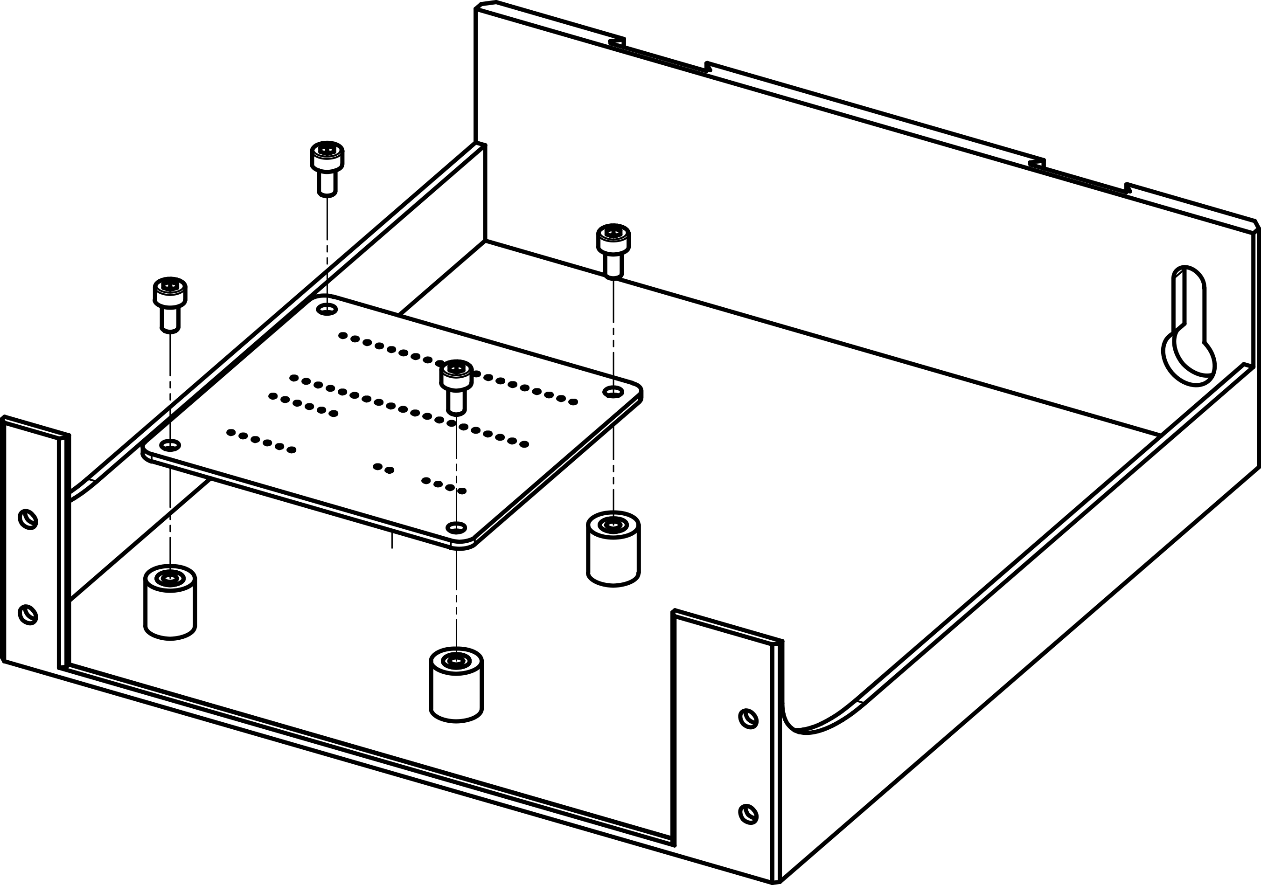
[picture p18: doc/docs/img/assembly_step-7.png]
Step 7


### Step 8 — Screw the facade to the drawer

Use the remaining 4 M3×6 hex socket head cap screws for this.

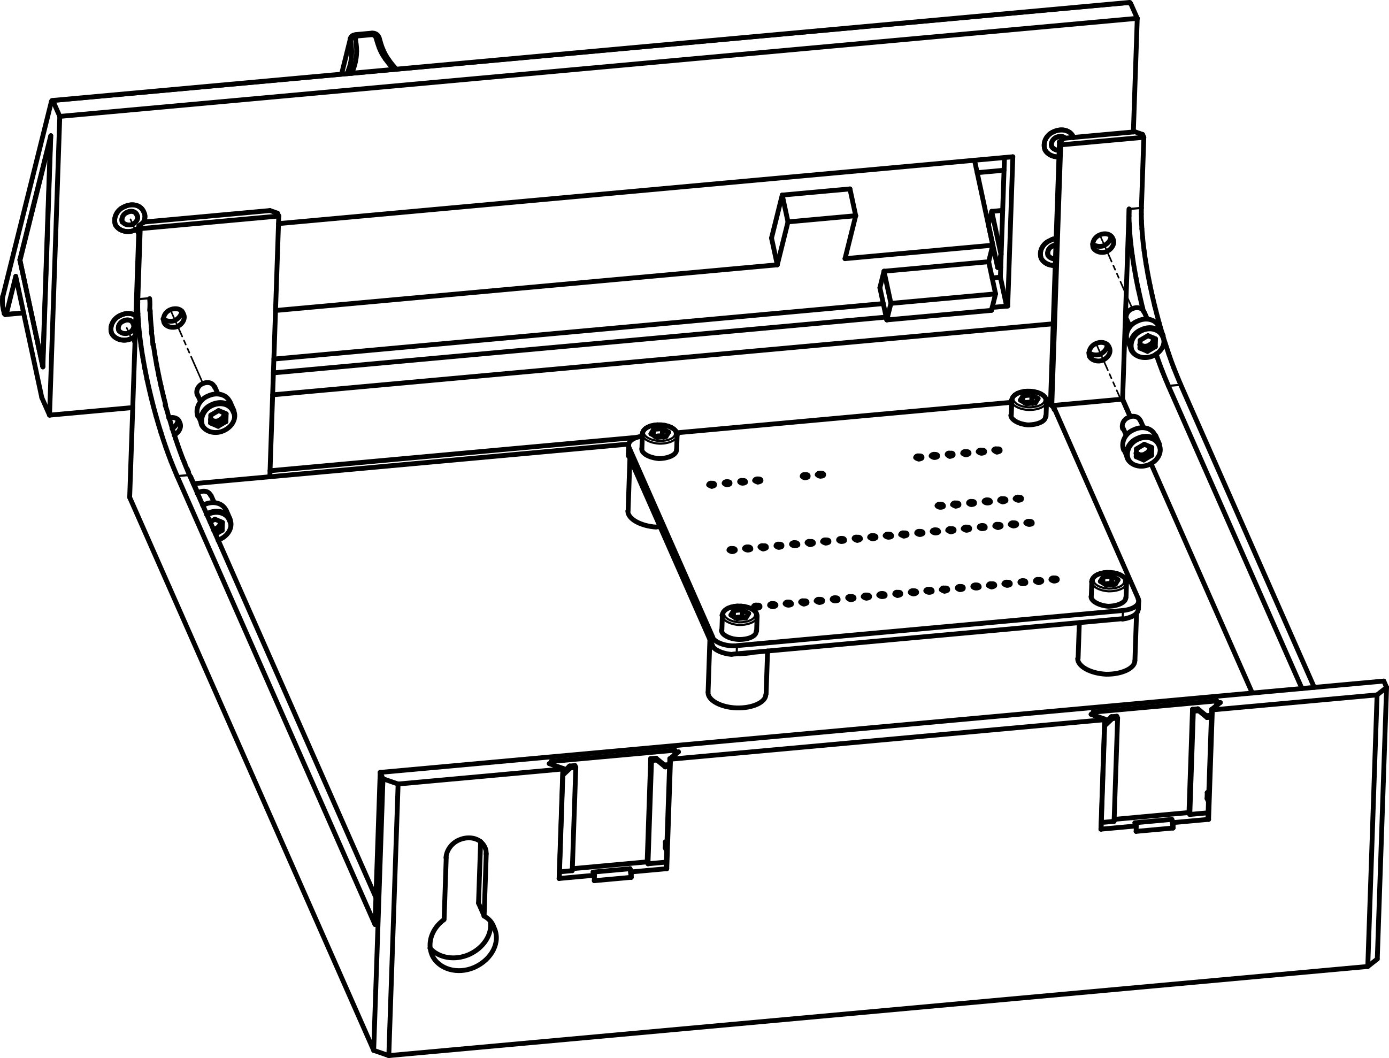
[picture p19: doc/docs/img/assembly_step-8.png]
Step 8


### Step 9 — Connect the cables

Now is time to connect the two cables that you have:

- Connect the 4 pin of the fader to the 4 pin of the PCB
- And connect the 2 pin of the motor to the 2 pin of the PCB

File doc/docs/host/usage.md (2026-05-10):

# Usage

Now that the software is installed:

- Make sure nothing is obstructing your knob. The calibration process will start immediately when the host program turns on
- Look for the "DHD Host" in your menu to start the program

You will get a small icon appearing in your systray, which tells you the state at all times.

## Calibration

When starting for the first time a calibration process happens. Don't worry, the results are saved on the device itself and remembered after reboot, so this will only happen once. You can however force a re-calibration for any reason (new knob with different weight, first calibration got interfered with, etc) by right-clicking the systray icon and selecting "Force Calibration".

## Scale Inversion

Another thing which you will probably need to do if you have the same setup as me, is that the potentiometer is mounted with 0% on the right and 100% on the left, which in many cultures is counter-intuitive for volume setting. In which case you can opt to invert the scale, and you will be left-to-right.

## Systray States

The systray icon reflects the current state:

| Icon | State | Meaning |
|---|---|---|
|  | Offline | Device not connected |
|  | Init | Connecting / handshake in progress |
|  | Calibration | Auto-calibration running |
|  | Ready | Standby, waiting for input |
|  | Hand | Physically driven (user moving fader) |
|  | Auto | Logically driven (computer moving fader) |
|  | Error | Failsafe / communication error |

## Signal Control

You can also control the daemon via Unix signals:

| Signal | Action |
|---|---|
| `SIGUSR1` | Force hard recalibration |
| `SIGUSR2` | Toggle scale inversion |

```bash
kill -USR1 $(pgrep dhd)
```

## CLI Reference

```
dhd [OPTIONS] [COMMAND]
```

### Options

| Option | Short | Description | Default |
|---|---|---|---|
| `--log-level <LEVEL>` | `-l` | Set device log level (`error`, `warn`, `info`, `debug`, `trace`) | `info` |
| `--systray` | `-s` | Enable system tray icon and detach from terminal | off |
| `--help` | `-h` | Print help | — |

The log level can also be set via the `DHD_LOG` environment variable.

### Subcommands

| Command | Description |
|---|---|
| `run` | Run the DHD host (default if no subcommand given) |
| `install` | Install the DHD host to autostart and system menu |

### Examples

```bash
# Run in foreground with debug logging
dhd -l debug

# Run as background daemon with systray
dhd --systray

# Install to autostart
dhd install
```

## Hardware Compatibility

The software makes few assumptions regarding the hardware, this way you can potentially hook up another fader out-of-the-box (modulo the exact screw locations) and it's likely that it will work decently. No alternative has been tested however.

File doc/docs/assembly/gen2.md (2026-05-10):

# GEN2 Integration

Not to cover the whole GEN2 documentation, but let's review the models that you will need.

Shortly put, the produced drawer is:

- Compatible with the 185 variant (which is the depth of the drawer, the most common)
- Dimensions are 2W×1H

## The Rail

First of all, if you want to do it like me, you'll need the under-desk rail. Get the [GEN2-QL Rail — Double](https://www.printables.com/model/1052357-gen2-rails-185-standard/files) file. Once printed you'll need self-tapping screws to screw it to the desk from underneath. I used [M4×20mm wood screws](https://amzn.eu/d/0ekTw1Um) for my Ikea desk, obviously measure before doing anything.

## The Case

Then you'll need the case. Basically cases are stacked underneath the rail, and have a rail of their own below so that you can append more cases below. For our drawer, we'll need the [185-2W-1H Case](https://www.printables.com/model/1658700-gen2-185-cases-all/files).

!!! warning "Case version"
    If you already have cases, make sure they are recent. For the USB to be able to go through the back, I'm using the wall attachment hole, which appeared on the 1st of April 2026. So if you've got an old file, it's not going to work out. As a corollary, you can't attach your case to the wall with this drawer, at least not without modifying it (and the case) a bit.

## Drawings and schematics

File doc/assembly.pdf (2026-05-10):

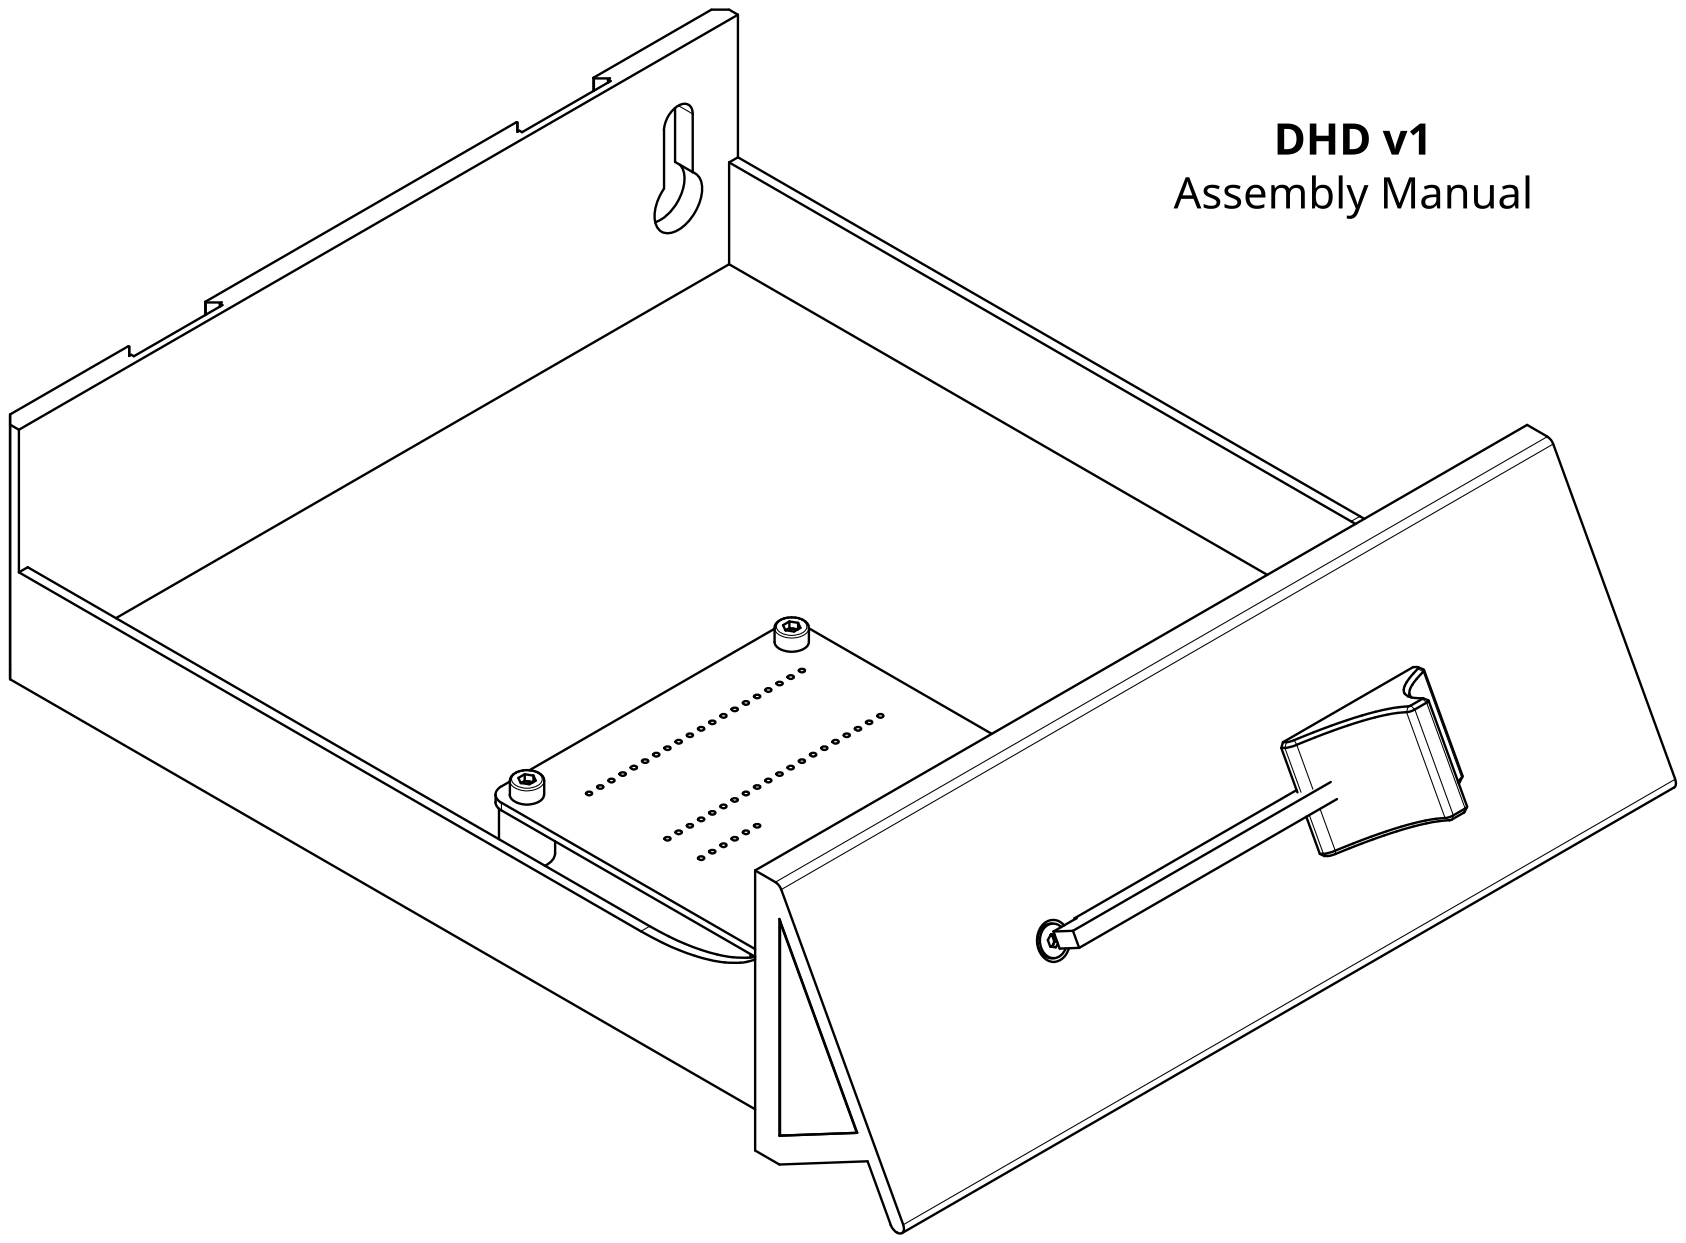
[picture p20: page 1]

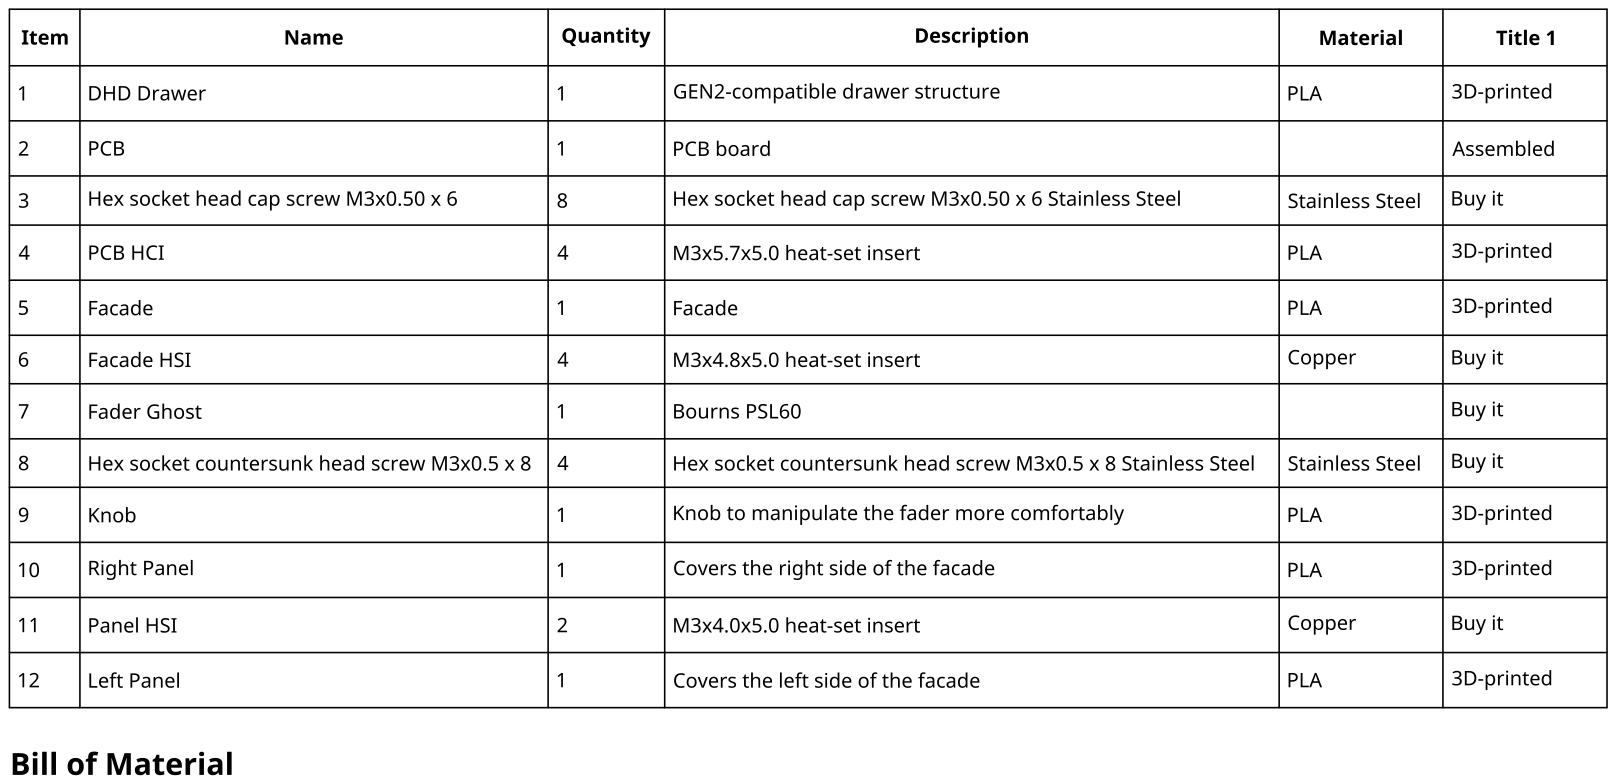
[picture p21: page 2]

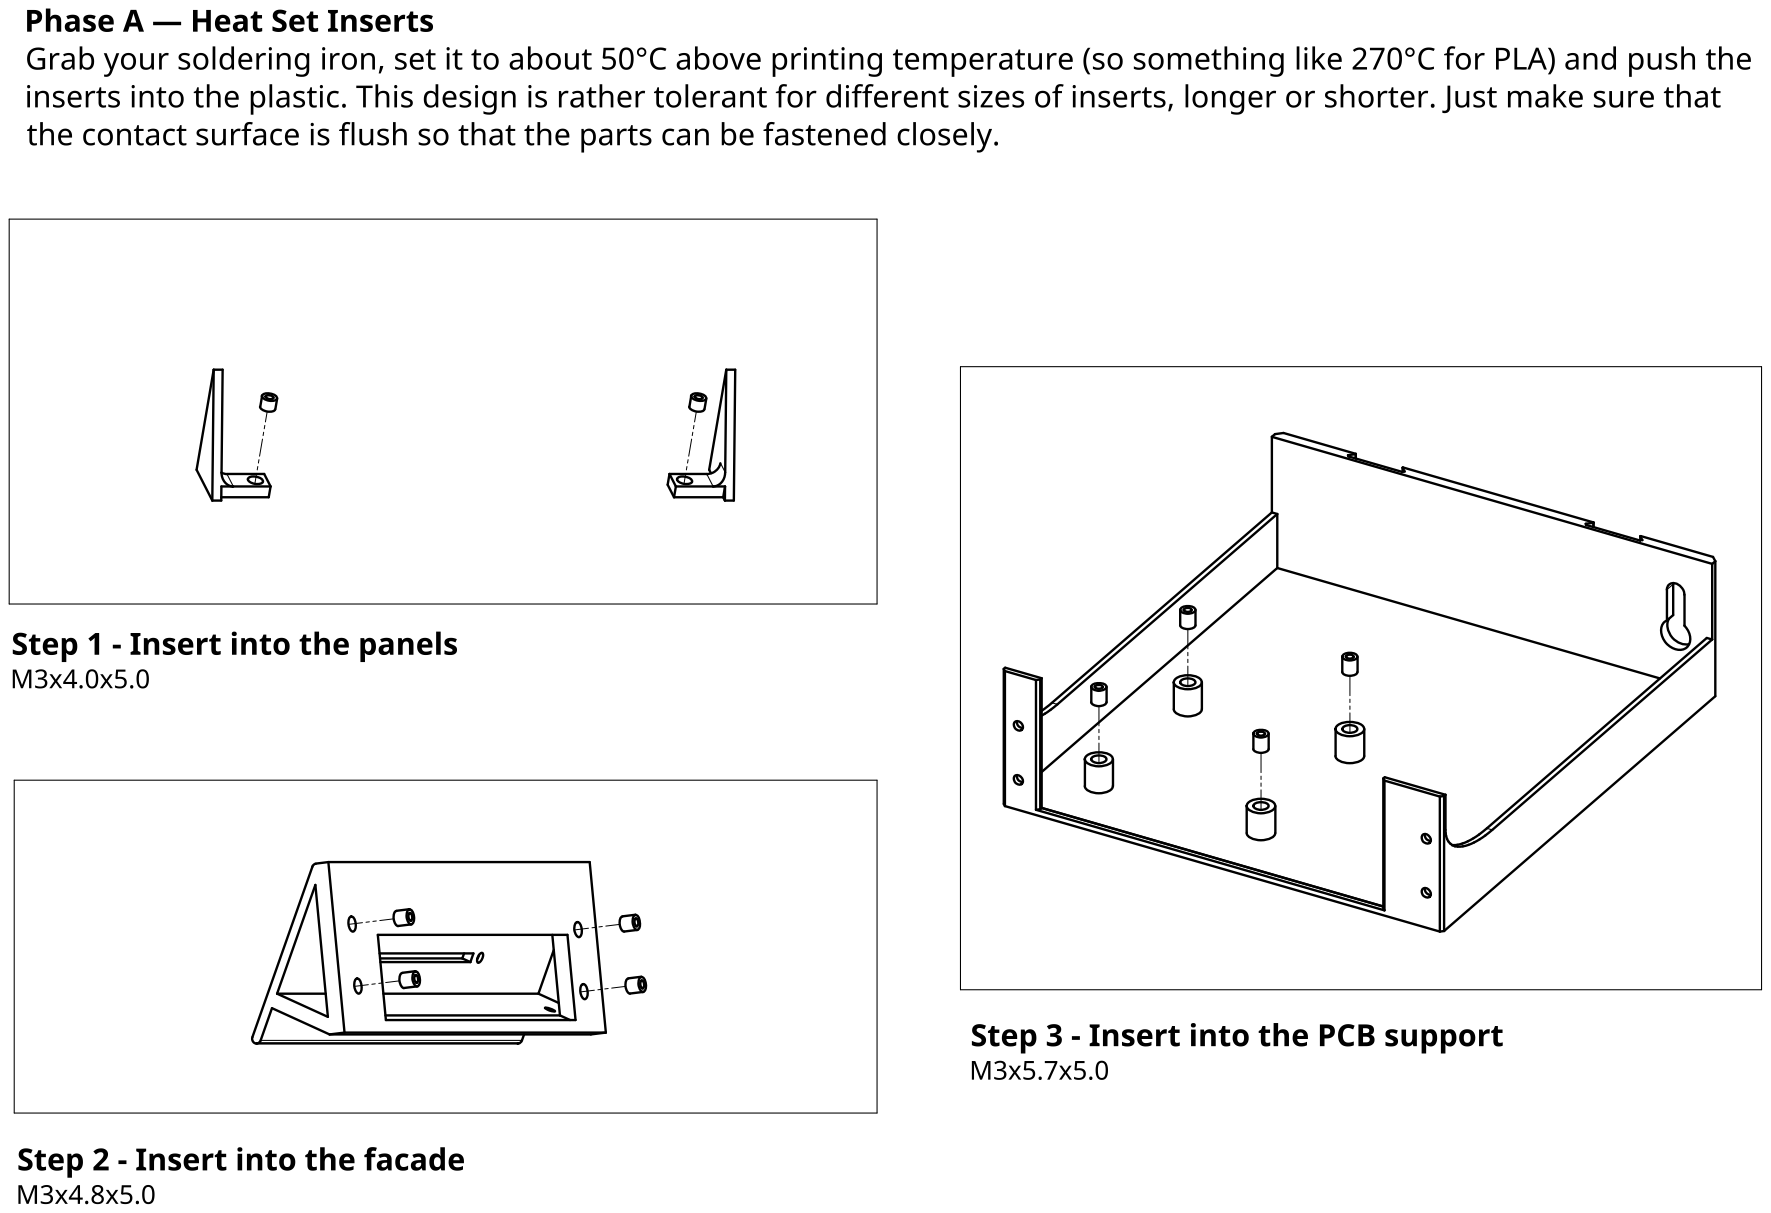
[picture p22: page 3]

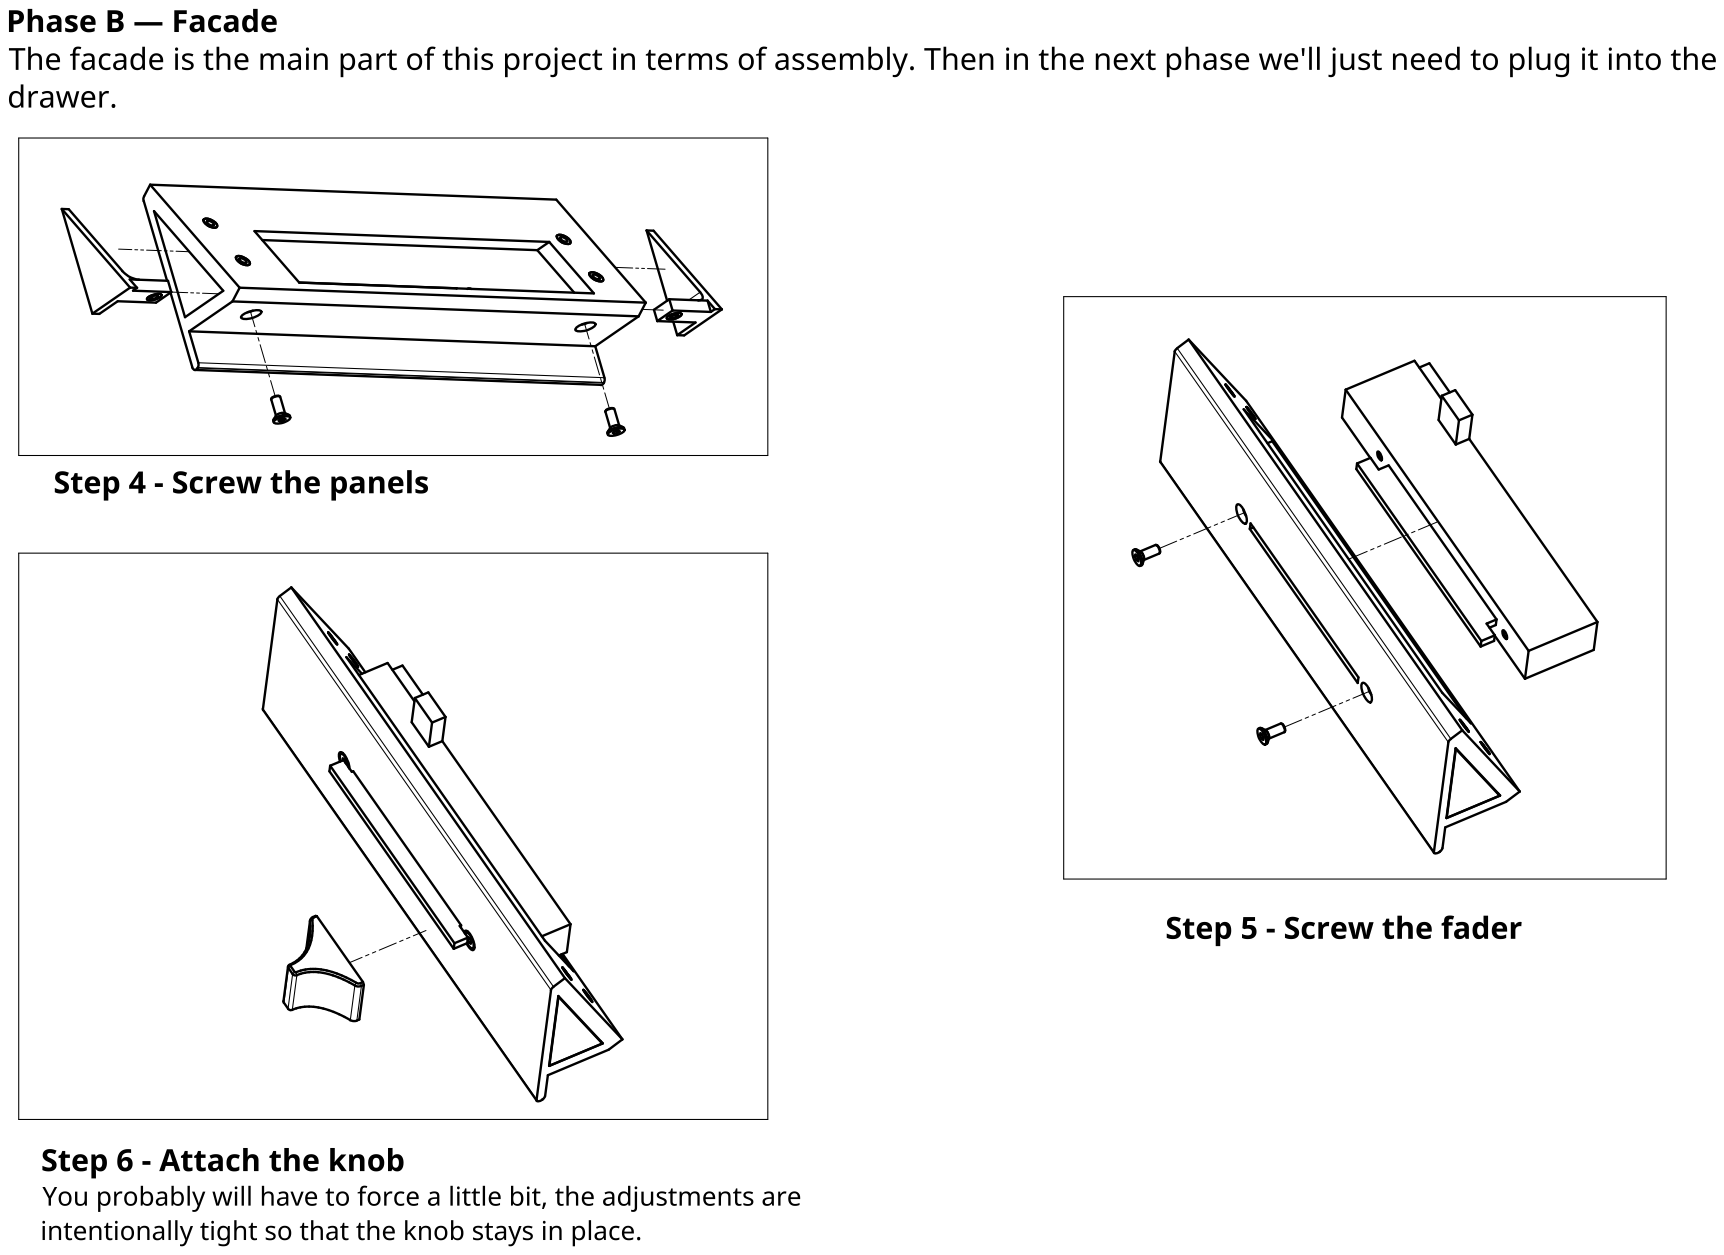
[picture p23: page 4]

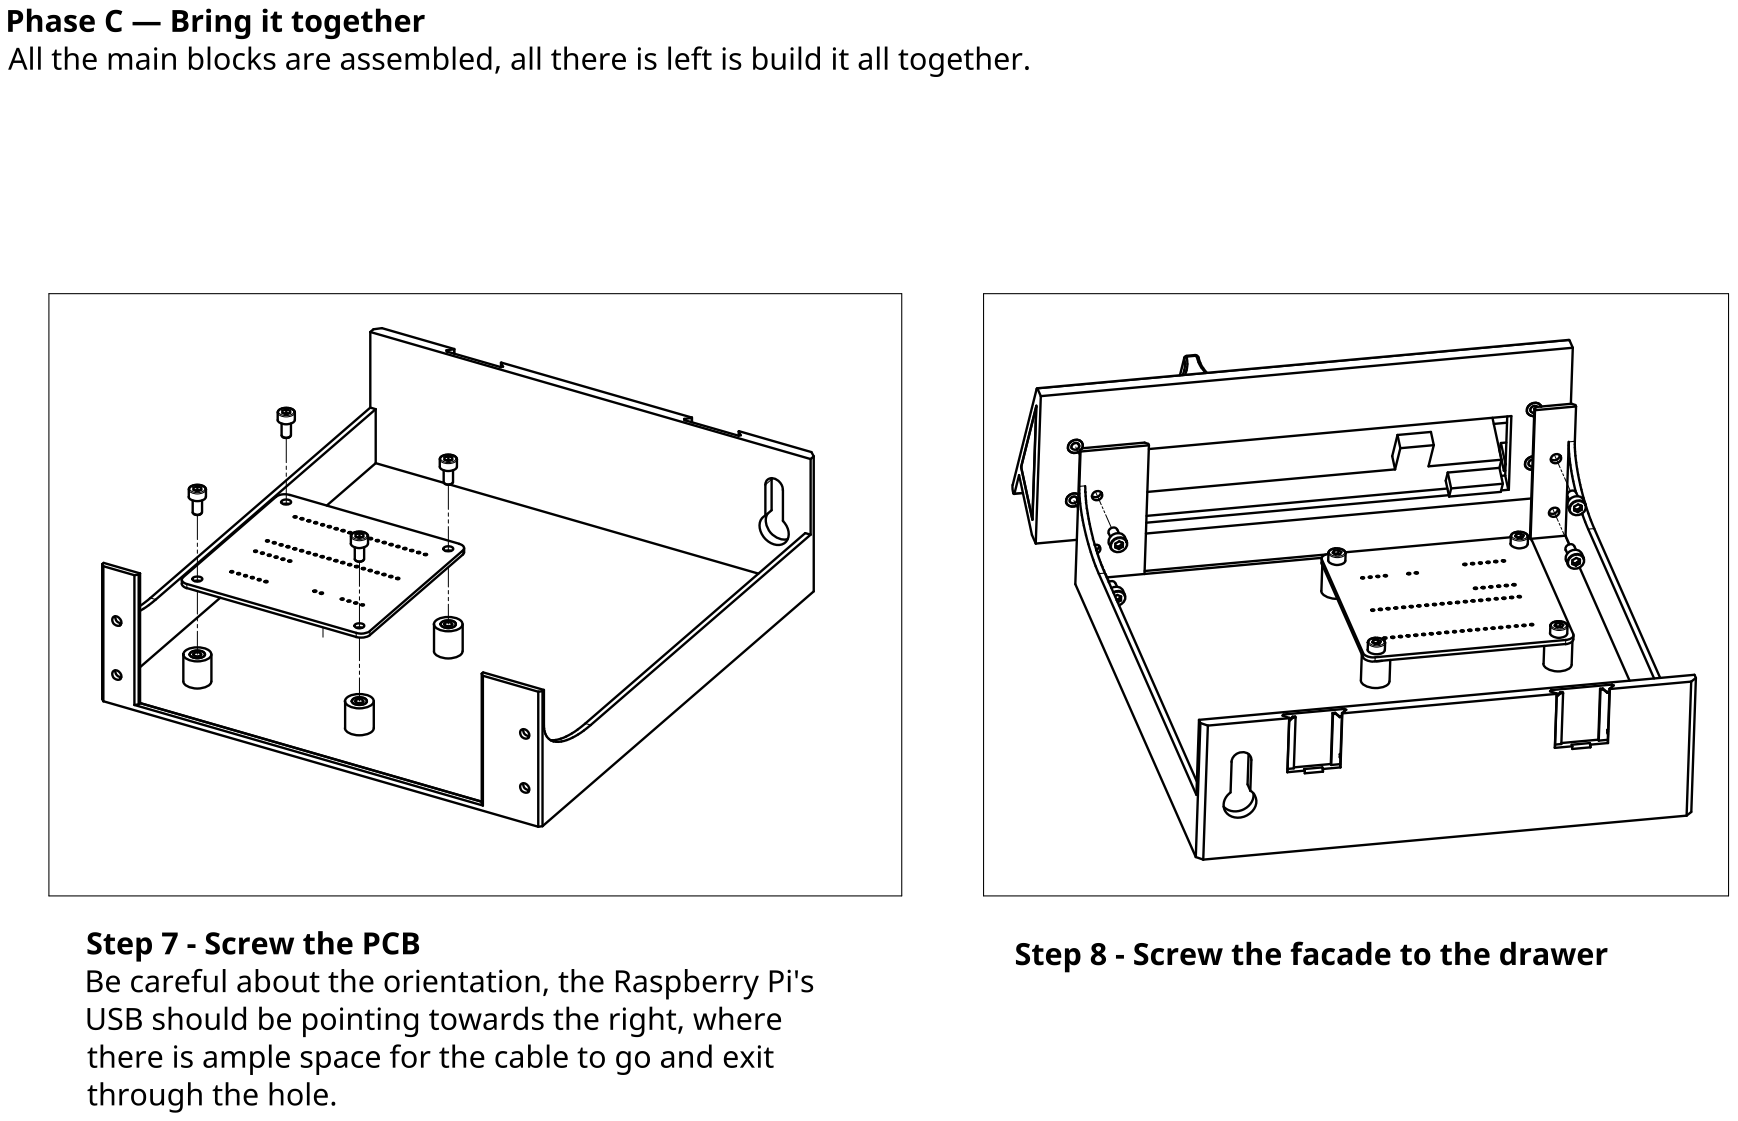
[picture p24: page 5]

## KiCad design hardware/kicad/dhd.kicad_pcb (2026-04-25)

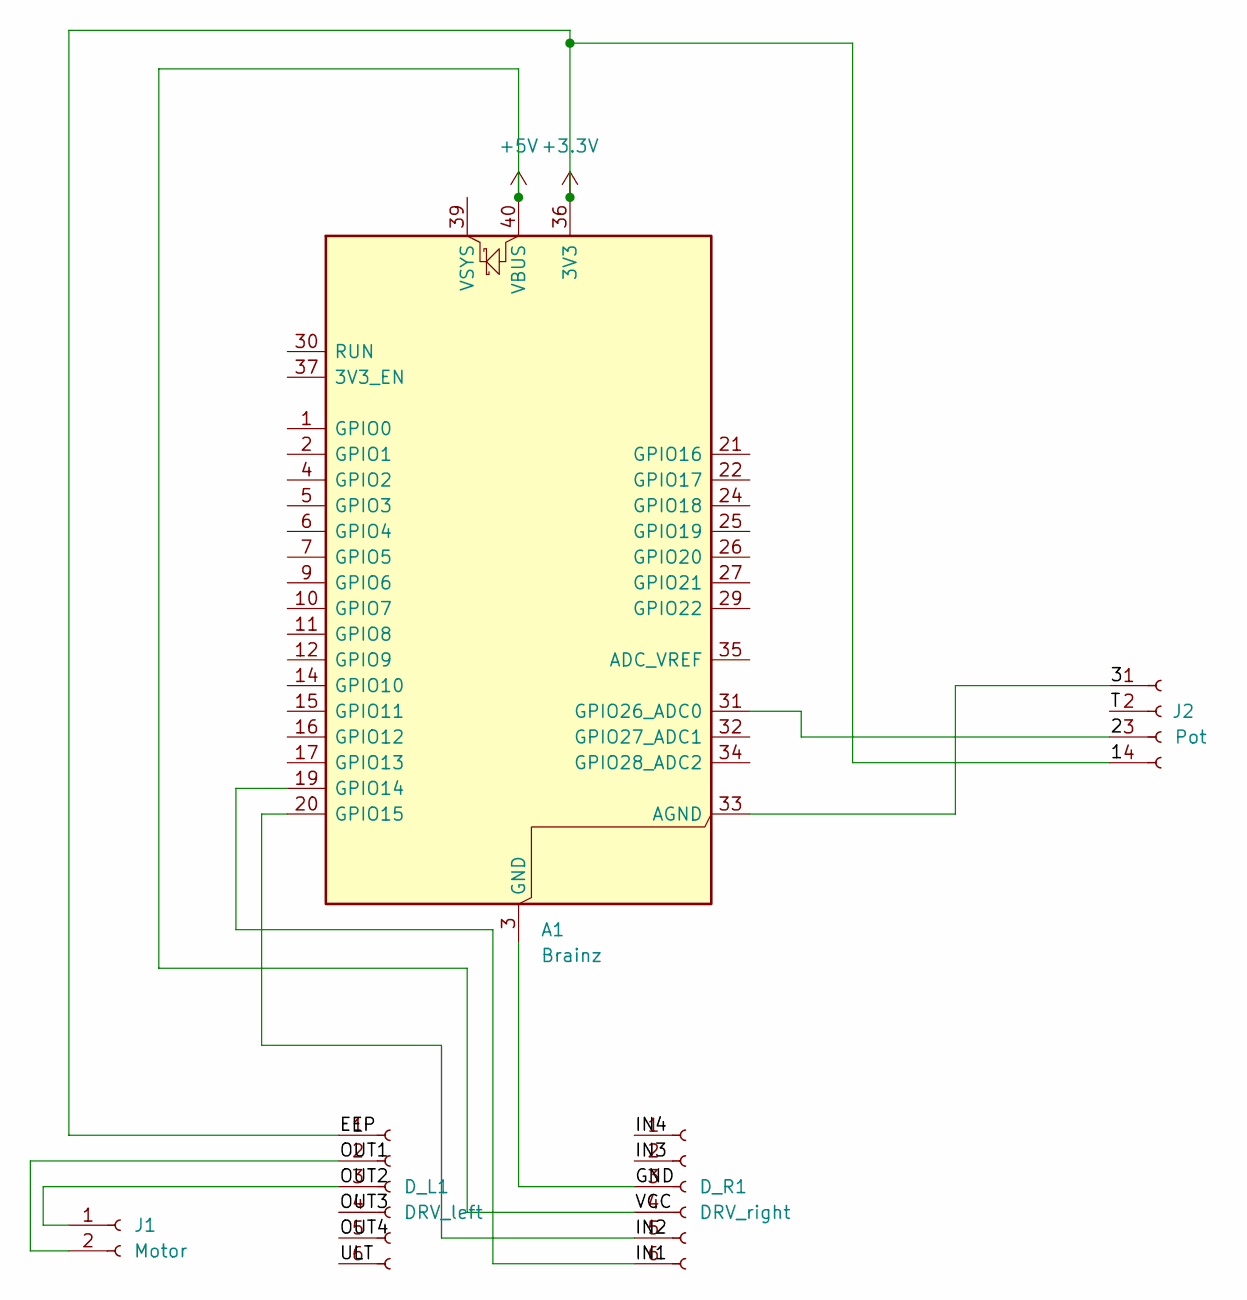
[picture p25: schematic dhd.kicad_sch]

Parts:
A1: Brainz; RaspberryPi_Pico_Common_THT
D_L1: DRV_left; PinHeader_1x06_P2.54mm_Vertical
D_R1: DRV_right; PinHeader_1x06_P2.54mm_Vertical
J1: Motor; JST_XH_B2B-XH-A_1x02_P2.50mm_Vertical
J2: Pot; JST_XH_B4B-XH-A_1x04_P2.50mm_Vertical

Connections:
+3.3V: A1.36 (3V3), D_L1.1, J2.4
+5V: A1.40 (VBUS), D_R1.4
/2: A1.31 (GPIO26_ADC0), J2.3
/3: A1.33 (AGND), J2.1
/GND: A1.3 (GND), A1.8 (GND), A1.13 (GND), A1.18 (GND), A1.23 (GND), A1.28 (GND), A1.38 (GND), D_R1.3
/IN1: A1.19 (GPIO14), D_R1.6
/IN2: A1.20 (GPIO15), D_R1.5
/IN3: D_R1.2
/IN4: D_R1.1
/OUT1: D_L1.2, J1.2
/OUT2: D_L1.3, J1.1
/OUT3: D_L1.4
/OUT4: D_L1.5
/T: J2.2
/ULT: D_L1.6

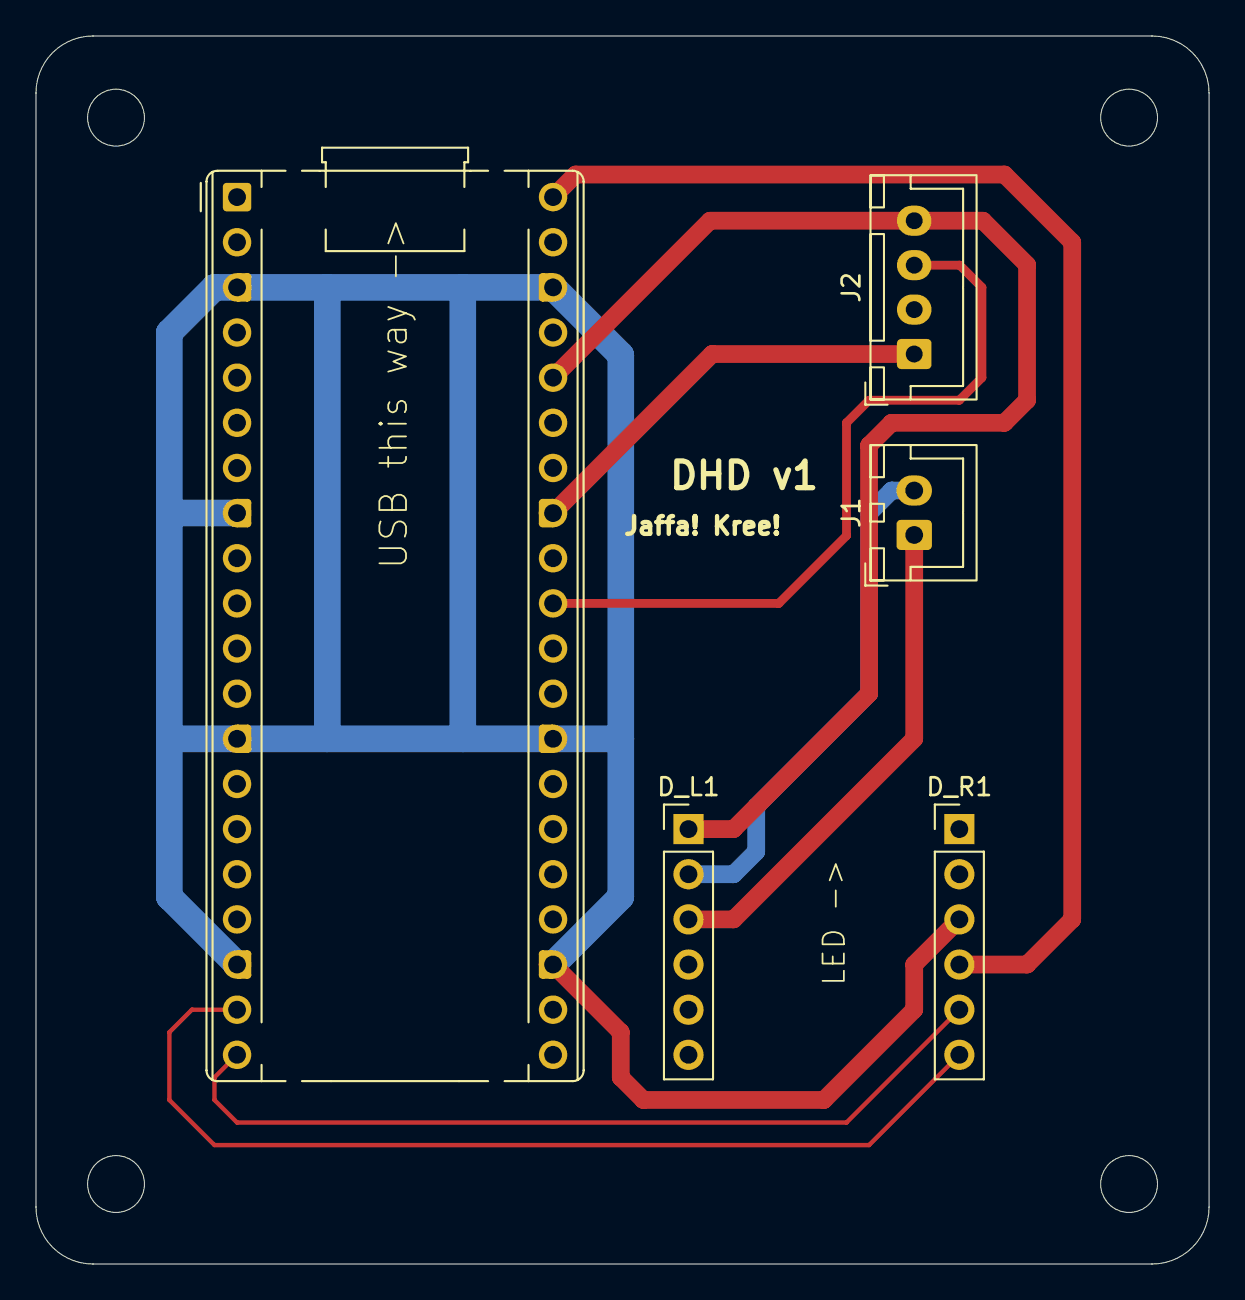
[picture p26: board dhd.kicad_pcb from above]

Board: 2 copper layers, 66.0 x 69.1 mm, 5 parts (0 on the bottom side), 9 nets.

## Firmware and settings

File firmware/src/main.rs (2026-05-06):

//! DHD (Dial Hifi Device) Firmware
//!
//! Domain-driven architecture for Raspberry Pi Pico 2.

#![no_std]
#![no_main]

mod comms;
mod fader;
mod system;
pub mod utils;

use core::sync::atomic::Ordering;
use embassy_executor::Spawner;
use embassy_futures::select::{Either3, Either4, select3, select4};
use embassy_rp::adc::InterruptHandler as AdcInterruptHandler;
use embassy_rp::adc::{Adc, Channel, Config as AdcConfig};
use embassy_rp::bind_interrupts;
use embassy_rp::dma::InterruptHandler as DmaInterruptHandler;
use embassy_rp::flash::{Async, Flash};
use embassy_rp::peripherals::{DMA_CH0, FLASH, USB};
use embassy_rp::pwm::{Config as PwmConfig, Pwm};
use embassy_rp::usb::Driver;
use embassy_rp::usb::InterruptHandler as UsbInterruptHandler;
use embassy_time::{Duration, Timer};
use embassy_usb::Builder;
use embassy_usb::Config as UsbConfig;
use embassy_usb::class::cdc_acm::{CdcAcmClass, State as CdcState};
use panic_halt as _;
use static_cell::StaticCell;

use crate::comms::{BUS as COMMS, reporter::task as reporter_task, usb::task as usb_task};
use crate::fader::{
    STATE as FADER, calibration::CalibrationService, interface::FaderInterface,
    reader::reader_task, service::fader_task,
};
use crate::system::storage::{FLASH_SIZE, load_calibration, store_calibration};
use crate::system::{STATE as SYSTEM, SystemMode, logger::LOGGER};
use common::OutgoingMessage;
use common::pid::{PidController, PidHardware};

bind_interrupts!(struct Irqs {
    USBCTRL_IRQ => UsbInterruptHandler<USB>;
    ADC_IRQ_FIFO => AdcInterruptHandler;
    DMA_IRQ_0 => DmaInterruptHandler<DMA_CH0>;
});

#[unsafe(link_section = ".bi_entries")]
#[used]
/// Embedded binary information for the picotool utility.
pub static PICOTOOL_ENTRIES: [embassy_rp::binary_info::EntryAddr; 4] = [
    embassy_rp::binary_info::rp_program_name!(c"DHD - Dial Hifi Device"),
    embassy_rp::binary_info::rp_program_description!(
        c"Physical media controller with haptic volume feedback"
    ),
    embassy_rp::binary_info::rp_cargo_version!(),
    embassy_rp::binary_info::rp_program_build_attribute!(),
];

/// Entry point for the firmware.
///
/// Initializes the RP2350 hardware, USB communication, ADC, and PWM.
/// Spawns the background tasks for USB handling, ADC reading, fader
/// interpolation, and host reporting.
/// Runs the main orchestrator state machine that coordinates system modes.
#[embassy_executor::main]
async fn main(spawner: Spawner) {
    let p = embassy_rp::init(Default::default());
    let _ = log::set_logger(&LOGGER);
    log::set_max_level(log::LevelFilter::Trace);

    // USB Driver Setup
    let driver = Driver::new(p.USB, Irqs);
    static CONFIG_DESC: StaticCell<[u8; 256]> = StaticCell::new();
    static BOS_DESC: StaticCell<[u8; 256]> = StaticCell::new();
    static CTRL_BUF: StaticCell<[u8; 64]> = StaticCell::new();
    static STATE: StaticCell<CdcState> = StaticCell::new();

    let mut config = UsbConfig::new(0x2e8a, 0x000a);
    config.manufacturer = Some("Offworld Nexus");
    config.product = Some("Dial Hifi Device");
    config.serial_number = Some("DHD-DEV");
    config.device_class = 0xEF;
    config.device_sub_class = 0x02;
    config.device_protocol = 0x01;
    config.composite_with_iads = true;

    let mut builder = Builder::new(
        driver,
        config,
        CONFIG_DESC.init([0; 256]),
        BOS_DESC.init([0; 256]),
        &mut [],
        CTRL_BUF.init([0; 64]),
    );
    let class = CdcAcmClass::new(&mut builder, STATE.init(CdcState::new()), 64);

    // Hardware setup
    let mut pwm_c = PwmConfig::default();
    pwm_c.top = 10000;
    let pwm = Pwm::new_output_ab(p.PWM_SLICE7, p.PIN_14, p.PIN_15, pwm_c);
    let adc = Adc::new(p.ADC, Irqs, AdcConfig::default());
    let channel = Channel::new_pin(p.PIN_26, embassy_rp::gpio::Pull::None);

    // Flash setup for persistent storage
    let mut flash = Flash::<_, Async, FLASH_SIZE>::new(p.FLASH, p.DMA_CH0, Irqs);

    // Domain infrastructure assembly
    let fader_hw = FaderInterface::new(pwm, &FADER);
    let mut cal_svc = CalibrationService::new(fader_hw);

    if let Some(cal) = load_calibration(&mut flash).await {
        log::info!("Loaded calibration from flash");
        *FADER.calibration.lock().await = cal;
    }

    // Spawn Domain tasks
    spawner.spawn(usb_task(builder, class, &FADER, &SYSTEM, &COMMS).unwrap());
    spawner.spawn(reader_task(adc, channel, &FADER, 21).unwrap());
    spawner.spawn(fader_task(&FADER).unwrap());
    spawner.spawn(reporter_task(&FADER, &SYSTEM, &COMMS).unwrap());

    // Orchestrator State Machine
    loop {
        match SYSTEM.get_mode() {
            SystemMode::Init => handle_init().await,
            SystemMode::Calibration => handle_calibration(&mut cal_svc, &mut flash, true).await,
            SystemMode::Standby => handle_standby(&mut cal_svc, &mut flash).await,
            SystemMode::LogicallyDriven => handle_logically_driven(&mut cal_svc).await,
            SystemMode::PhysicallyDriven => handle_physically_driven(&mut cal_svc).await,
            SystemMode::Failsafe => handle_failsafe().await,
        }
    }
}

/// Initializes the device connection.
///
/// Waits for the initial handshake to complete with the host, ensuring the USB
/// CDC-ACM connection is fully established. It then drains any pending outgoing
/// messages (excluding the handshake sequence already queued) before
/// transitioning the system to the `Standby` state.
async fn handle_init() {
    SYSTEM.sig_handshake_done.wait().await;
    while COMMS.chan_outgoing.try_receive().is_ok() {}
    SYSTEM.set_mode(SystemMode::Standby);
}

/// Executes the dual-stage calibration routine.
///
/// First, it runs a physical calibration to detect the hard mechanical stops
/// (0% and 100%) and saves these boundaries to ensure safe motor operation.
/// Next, it performs an autotune sequence to calculate the PID coefficients
/// (Kp, Ki, Kd) necessary for precise logical driving.
/// Finally, it moves the fader to the initial logical volume requested by the
/// host before transitioning into the `Standby` state.
async fn handle_calibration(
    cal_svc: &mut CalibrationService,
    flash: &mut Flash<'_, FLASH, Async, FLASH_SIZE>,
    force: bool,
) {
    SYSTEM.set_mode(SystemMode::Calibration);

    let mut needs_run = force;
    if !force {
        let cal = FADER.calibration.lock().await;
        if cal.physical.boundaries.max <= cal.physical.boundaries.min {
            needs_run = true;
        }
    }

    if needs_run {
        log::info!("Starting physical calibration...");
        let physical = cal_svc.run_physical_calibration().await;
        FADER.calibration.lock().await.physical = physical;

        log::info!("Starting PID calibration...");
        let pid_cal = cal_svc.run_pid_calibration().await;
        let cal_to_save = {
            let mut cal = FADER.calibration.lock().await;
            cal.pid = pid_cal;
            *cal
        };
        store_calibration(flash, &cal_to_save).await;
    } else {
        log::info!("Calibration already exists, skipping re-calibration");
    }

    log::info!("All calibrations complete.");

    let pid_cal = FADER.calibration.lock().await.pid;
    let target: f32 = FADER.target_volume_ppm.load(Ordering::Relaxed) as f32 / 1_000_000.0;
    log::debug!("Moving to final target: {:.2}", target);

    let hw = cal_svc.take_fader();
    let mut pid = PidController::<_, 50>::new(hw, pid_cal.kp, pid_cal.ki, pid_cal.kd, 0.0);
    pid.alpha = pid_cal.alpha;
    pid.deadband_frac = pid_cal.deadband;

    pid.run_until_target(target).await;

    pid.hardware.write_output(0.0).await;
    cal_svc.return_fader(pid.hardware);

    FADER.sig_target_vol_changed.reset();
    FADER.sig_vol_changed.reset();
    SYSTEM.set_mode(SystemMode::Standby);
}

/// Handles the idle state of the device.
///
/// In standby, the motor is completely disengaged. This function awaits external
/// triggers to change the system mode:
/// - A host-requested calibration -> `Calibration`
/// - A volume update from the host -> `LogicallyDriven`
/// - Physical movement detected from the user -> `PhysicallyDriven`
/// - A scale inversion toggle request -> toggles, persists, and reports
async fn handle_standby(
    cal_svc: &mut CalibrationService,
    flash: &mut Flash<'_, FLASH, Async, FLASH_SIZE>,
) {
    match select4(
        SYSTEM.sig_start_calib.wait(),
        FADER.sig_target_vol_changed.wait(),
        FADER.sig_vol_changed.wait(),
        SYSTEM.sig_invert_scale.wait(),
    )
    .await
    {
        Either4::First(force) => {
            handle_calibration(cal_svc, flash, force).await;
        }
        Either4::Second(_) => {
            SYSTEM.set_mode(SystemMode::LogicallyDriven);
        }
        Either4::Third(_) => {
            SYSTEM.set_mode(SystemMode::PhysicallyDriven);
        }
        Either4::Fourth(_) => {
            handle_invert_scale(flash).await;
        }
    }
}

/// Toggles the scale inversion state, persists it to flash, and reports
/// the new state to the host.
///
/// When scale inversion is enabled, a hardware reading of 100% maps to
/// volume 0% and vice-versa. This setting is stored alongside calibration
/// data in flash so it persists across reboots.
async fn handle_invert_scale(flash: &mut Flash<'_, FLASH, Async, FLASH_SIZE>) {
    let (new_inverted, cal_to_save) = {
        let mut cal = FADER.calibration.lock().await;
        cal.inverted = !cal.inverted;
        log::info!(
            "Scale inversion toggled: {}",
            if cal.inverted { "ON" } else { "OFF" }
        );
        (cal.inverted, *cal)
    };

    store_calibration(flash, &cal_to_save).await;

    let _ = COMMS
        .chan_outgoing
        .try_send(OutgoingMessage::ScaleInverted {
            inverted: new_inverted,
        });

    // Trigger a volume re-read so the new inversion is immediately reflected
    FADER.sig_range_updated.signal(());
}

/// Handles the logic for `LogicallyDriven` mode.
///
/// In this mode, the system acts as an output device for the host. The host
/// sends volume updates which the PID controller must track. The `fader_task`
/// continuously runs the filter and updates `sig_vol_changed`. The PID
/// controller runs until it reaches the target volume and the plant settles
/// mechanically (signaled by `!pid.was_driving`).
///
/// If the host sends a new target while the fader is still moving to the
/// previous one, the inner loop is interrupted and restarts with the new
/// target. If the PID takes longer than 1 second to settle on a single target,
/// it times out and aborts to prevent burning out the motor.
async fn handle_logically_driven(cal_svc: &mut CalibrationService) {
    log::info!("Mode: LogicallyDriven");
    let cal_data = FADER.calibration.lock().await;
    let mut pid = PidController::<_, 50>::new(
        cal_svc.take_fader(),
        cal_data.pid.kp,
        cal_data.pid.ki,
        cal_data.pid.kd,
        0.0,
    );
    pid.alpha = cal_data.pid.alpha;
    pid.deadband_frac = cal_data.pid.deadband;
    drop(cal_data);

    loop {
        FADER.sig_target_vol_changed.reset();
        let target: f32 = FADER.target_volume_ppm.load(Ordering::Relaxed) as f32 / 1_000_000.0;

        match select3(
            pid.run_until_target(target),
            FADER.sig_target_vol_changed.wait(),
            Timer::after(Duration::from_secs(1)),
        )
        .await
        {
            Either3::First(_) => break,     // Reached target
            Either3::Second(_) => continue, // New target, restart loop
            Either3::Third(_) => {
                log::warn!("LogicallyDriven timed out");
                break;
            }
        }
    }

    pid.hardware.write_output(0.0).await;
    cal_svc.return_fader(pid.hardware);
    FADER.sig_vol_changed.reset();
    SYSTEM.set_mode(SystemMode::Standby);
}

/// Handles the logic for `PhysicallyDriven` mode.
///
/// This mode is activated when the user physically manipulates the fader knob.
/// The purpose of this mode is to allow the user to freely change the volume,
/// which is then reported back to the host.
///
/// To prevent feedback resonance, the motor is completely disengaged (output
/// set to `0.0`). The system simply waits and observes `sig_vol_changed`. If
/// no volume changes occur for 1 full second, it is assumed the user has
/// stopped touching the fader, and the system transitions back to `Standby`.
async fn handle_physically_driven(cal_svc: &mut CalibrationService) {
    log::info!("Mode: PhysicallyDriven");

    // Disable motor for physical movements
    let mut hw = cal_svc.take_fader();
    hw.write_output(0.0).await;

    // Wait until no physical movement is detected for 1 second
    while let embassy_futures::select::Either::First(_) = embassy_futures::select::select(
        FADER.sig_vol_changed.wait(),
        Timer::after(Duration::from_secs(1)),
    )
    .await
    {
        // Movement detected, continue waiting
    }

    cal_svc.return_fader(hw);

    // Explicitly reset the volume changed signal to avoid immediate re-entry
    FADER.sig_vol_changed.reset();
    SYSTEM.set_mode(SystemMode::Standby);
}

/// A fallback mode entered if a critical subsystem crashes or an irrecoverable
/// error occurs.
///
/// Once in Failsafe mode, the device halts all operations and waits
/// indefinitely, requiring a hard reset or power cycle to recover.
async fn handle_failsafe() {
    log::warn!("Failsafe mode");
    loop {
        embassy_futures::yield_now().await;
    }
}

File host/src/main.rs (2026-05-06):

//! DHD (Dial Hifi Device) Host Tool
//!
//! This application runs on the host computer and communicates with the DHD
//! device over a virtual serial port (CDC-ACM). It provides:
//! - Automatic device discovery and reconnection.
//! - Real-time volume monitoring with visual feedback.
//! - Diagnostic log display from the device.
//! - Health monitoring via periodic pings.

use anyhow::{Context as _, Result};
use chrono::Local;
use colored::*;
use common::{IncomingMessage, OutgoingMessage, SystemMode};
use fs2::FileExt;
use futures::{SinkExt, StreamExt};
use ksni::TrayMethods;
use libpulse_binding as pulse;
use pulse::context::subscribe::Facility;
use pulse::context::{Context, State};
use pulse::mainloop::threaded::Mainloop;
use pulse::volume::{ChannelVolumes, Volume};
use std::path::PathBuf;
use std::sync::{Arc, Mutex};
use std::time::Duration;
use tokio::time::interval;
use tokio_serial::{SerialPortBuilderExt, SerialStream};
use tokio_util::codec::{Framed, LinesCodec};

/// Raspberry Pi Pico Vendor ID.
const VID: u16 = 0x2e8a;
/// Raspberry Pi Pico CDC-ACM Product ID.
const PID: u16 = 0x000a;

use clap::{Parser, Subcommand, ValueEnum};
use tokio::signal::unix::{SignalKind, signal};
use tokio::sync::mpsc;

/// DHD (Dial Hifi Device) Host Tool
#[derive(Parser, Debug)]
#[command(author, version, about, long_about = None)]
struct Cli {
    #[command(subcommand)]
    command: Option<Commands>,

    /// Set the log level for the device
    #[arg(short, long, value_enum, default_value_t = LogLevel::Info, env = "DHD_LOG")]
    log_level: LogLevel,

    /// Enable system tray icon and detach from terminal
    #[arg(short, long)]
    systray: bool,
}

#[derive(Subcommand, Debug)]
enum Commands {
    /// Run the DHD host (default)
    Run,
    /// Install the DHD host to autostart and system menu
    Install,
}

#[derive(ValueEnum, Clone, Debug, PartialEq, PartialOrd)]
enum LogLevel {
    Error,
    Warn,
    Info,
    Debug,
    Trace,
}

impl LogLevel {
    fn from_str(s: &str) -> Self {
        match s {
            "ERROR" => LogLevel::Error,
            "WARN" => LogLevel::Warn,
            "INFO" => LogLevel::Info,
            "DEBUG" => LogLevel::Debug,
            "TRACE" => LogLevel::Trace,
            _ => LogLevel::Info,
        }
    }
}

/// PulseAudio events we want to handle.
enum PulseEvent {
    ServerChange,
    SinkChange(u32),
}

#[derive(Default)]
struct PulseCache {
    sink_index: Option<u32>,
    num_channels: u8,
    last_volume: ChannelVolumes,
}

/// PulseAudio controller for system volume adjustment.
struct PulseController {
    mainloop: Mainloop,
    context: Context,
    cache: Arc<Mutex<PulseCache>>,
    vol_tx: mpsc::UnboundedSender<f32>,
}

struct DhdTray {
    connected: bool,
    mode: SystemMode,
    inverted: bool,
    sig_tx: mpsc::UnboundedSender<()>,
    invert_tx: mpsc::UnboundedSender<()>,
}

impl ksni::Tray for DhdTray {
    fn id(&self) -> String {
        "dhd-host".into()
    }

    fn icon_name(&self) -> String {
        let name = if self.connected {
            match self.mode {
                SystemMode::Init => "dhd-init",
                SystemMode::Calibration => "dhd-calib",
                SystemMode::Standby => "dhd-ready",
                SystemMode::Failsafe => "dhd-error",
                SystemMode::PhysicallyDriven => "dhd-hand",
                SystemMode::LogicallyDriven => "dhd-auto",
            }
        } else {
            "dhd-offline"
        };

        let home = std::env::var("HOME").unwrap_or_default();
        let installed_path = PathBuf::from(home)
            .join(".local/share/dhd/assets")
            .join(format!("{}.svg", name));

        installed_path.to_string_lossy().into_owned()
    }

    fn title(&self) -> String {
        let emoji = if self.connected {
            match self.mode {
                SystemMode::Init => "⏳",
                SystemMode::Calibration => "⚖️",
                SystemMode::Standby => "😴",
                SystemMode::Failsafe => "🚨",
                SystemMode::PhysicallyDriven => "🖐️",
                SystemMode::LogicallyDriven => "🤖",
            }
        } else {
            "❌"
        };
        format!("{} DHD", emoji)
    }

    fn tool_tip(&self) -> ksni::ToolTip {
        let status = if self.connected {
            match self.mode {
                SystemMode::Init => "Initializing...",
                SystemMode::Calibration => "Calibrating...",
                SystemMode::Standby => "Standby",
                SystemMode::Failsafe => "FAILSAFE!",
                SystemMode::PhysicallyDriven => "Physically Driven",
                SystemMode::LogicallyDriven => "Logically Driven",
            }
        } else {
            "Disconnected"
        };
        ksni::ToolTip {
            title: "DHD Host".into(),
            description: status.into(),
            ..Default::default()
        }
    }

    fn menu(&self) -> Vec<ksni::MenuItem<Self>> {
        use ksni::menu::*;
        vec![
            StandardItem {
                label: "Force Calibration".into(),
                enabled: self.connected,
                activate: Box::new(|this: &mut Self| {
                    let _ = this.sig_tx.send(());
                }),
                ..Default::default()
            }
            .into(),
            CheckmarkItem {
                label: "Invert Scale".into(),
                enabled: self.connected,
                checked: self.inverted,
                activate: Box::new(|this: &mut Self| {
                    let _ = this.invert_tx.send(());
                }),
                ..Default::default()
            }
            .into(),
            MenuItem::Separator,
            StandardItem {
                label: "Quit".into(),
                activate: Box::new(|_| {
                    std::process::exit(0);
                }),
                ..Default::default()
            }
            .into(),
        ]
    }
}

unsafe impl Send for PulseController {}
unsafe impl Sync for PulseController {}

fn log(_tag: &str, color: ColoredString, message: impl AsRef<str>) {
    let now = Local::now().format("%H:%M:%S%.3f").to_string().dimmed();
    println!("{} [{}] {}", now, color.bold(), message.as_ref());
}
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

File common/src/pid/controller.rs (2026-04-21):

use super::hardware::PidHardware;

/// A PID controller for second-order mechanical plants (mass + friction).
///
/// Design choices:
/// - **Derivative on measurement velocity** (not on error). Velocity is estimated via an
///   EMA on position; the D term is `-Kd * velocity`. This avoids setpoint-kick and is
///   much friendlier with noisy ADCs than differentiating error.
/// - **Integral with anti-windup**. The integral only accumulates when the output is not
///   saturated in the same direction we're driving.
/// - **Hysteretic friction compensation**. Rather than an always-on friction lift (which
///   creates a ±min_gain discontinuity at zero error and causes limit cycles), we use
///   hysteresis: we only engage the motor when |error| > engage_band, and we only add the
///   min_gain floor when the PID value is already pushing in a direction with enough
///   magnitude to warrant breaking stiction. Otherwise we output 0.
/// - **Adaptive deadband**. The deadband scales with the estimated measurement noise so
///   we don't chatter on noise.
pub struct PidController<H: PidHardware, const N: usize> {
    /// Hardware interface for reading and writing.
    pub hardware: H,
    /// Proportional gain.
    pub kp: f32,
    /// Integral gain.
    pub ki: f32,
    /// Derivative gain (applied to measurement velocity).
    pub kd: f32,
    /// Feed-forward gain (applied to target).
    pub kf: f32,
    /// Current target setpoint.
    pub target: f32,

    /// Accumulated integral of error.
    pub(super) integral: f32,

    /// Current low-pass filtered position.
    pub(super) filt_pos: f32,
    /// Previous low-pass filtered position (for velocity estimation).
    pub(super) filt_pos_prev: f32,
    /// Whether the filter has been initialized with the first measurement.
    pub(super) filt_init: bool,

    /// EMA filter coefficient for position (0..1).
    pub alpha: f32,

    /// Deadband as a fraction of measurement range. Configured by calibration.
    pub deadband_frac: f32,

    /// Hysteresis state: whether the motor was driven on the previous step.
    pub was_driving: bool,
}

impl<H: PidHardware, const N: usize> PidController<H, N> {
    /// Create a new PID controller with given coefficients.
    pub fn new(hardware: H, kp: f32, ki: f32, kd: f32, kf: f32) -> Self {
        Self {
            hardware,
            kp,
            ki,
            kd,
            kf,
            target: 0.0,
            integral: 0.0,
            filt_pos: 0.0,
            filt_pos_prev: 0.0,
            filt_init: false,
            alpha: 0.35,
            deadband_frac: 0.005,
            was_driving: false,
        }
    }

    /// Update the target setpoint.
    pub fn set_target(&mut self, target: f32) {
        self.target = target;
    }

    /// Update all PID coefficients.
    pub fn set_coefficients(&mut self, kp: f32, ki: f32, kd: f32, kf: f32) {
        self.kp = kp;
        self.ki = ki;
        self.kd = kd;
        self.kf = kf;
    }

    /// Borrow the underlying hardware interface.
    pub fn hardware(&mut self) -> &mut H {
        &mut self.hardware
    }

    /// Reset internal state (integral and filter).
    pub fn reset_history(&mut self) {
        self.integral = 0.0;
        self.filt_init = false;
        self.was_driving = false;
    }

    /// Set the EMA filter alpha (responsiveness of velocity estimation).
    pub fn set_filter_alpha(&mut self, alpha: f32) {
        self.alpha = alpha.clamp(0.05, 1.0);
    }

    /// Fraction of measurement range used as the inner deadband (engage band = 1.5x this).
    pub fn set_deadband(&mut self, deadband_frac: f32) {
        self.deadband_frac = deadband_frac.clamp(0.0005, 0.1);
    }

    /// Update the velocity estimate using an Exponential Moving Average (EMA) filter.
    ///
    /// This provides a smooth velocity signal for the derivative term, which is
    /// much less susceptible to ADC noise than differentiating the raw error.
    fn update_velocity_estimate(&mut self, measurement: f32) -> f32 {
        if !self.filt_init {
            self.filt_pos = measurement;
            self.filt_pos_prev = measurement;
            self.filt_init = true;
        } else {
            self.filt_pos_prev = self.filt_pos;
            self.filt_pos = self.filt_pos + self.alpha * (measurement - self.filt_pos);
        }
        self.filt_pos - self.filt_pos_prev
    }

    /// Check the hysteretic deadband to determine if the motor should be driven.
    ///
    /// This prevents the motor from "hunting" around the target due to ADC noise.
    /// - If currently driving, we only stop when within the inner band and velocity is low.
    /// - If currently idle, we only start driving when the error exceeds the outer band.
    fn should_drive(&mut self, error: f32, velocity: f32, range: f32) -> bool {
        let inner_band = self.deadband_frac * range;
        let outer_band = 1.5 * inner_band;

        if self.was_driving {
            // Currently driving: stop only when we've clearly arrived AND we're not moving fast.
            let vel_settled = velocity.abs() < 0.001 * range;
            if error.abs() < inner_band && vel_settled {
                self.was_driving = false;
                return false;
            }
            true
        } else {
            // Currently idle: only re-engage when error exceeds outer band.
            if error.abs() < outer_band {
                return false;
            }
            self.was_driving = true;
            // Re-reset integral on re-engage so old wind-up doesn't bite us.
            self.integral = 0.0;
            true
        }
    }

    /// Calculate the raw PID control effort.
    ///
    /// This includes proportional, integral (with anti-windup), derivative (on measurement),
    /// and feed-forward terms. The output represents the desired force *above* the stiction floor.
    fn calculate_pid_effort(
        &mut self,
        error: f32,
        velocity: f32,
        min_mag: f32,
        max_mag: f32,
    ) -> f32 {
        let p_term = self.kp * error;
        let d_term = -self.kd * velocity;
        let ff_term = self.kf * self.target;

        // Tentative integral update.
        let mut new_integral = self.integral + error;
        let i_term_tentative = self.ki * new_integral;
        let u_tentative = p_term + i_term_tentative + d_term + ff_term;

        // Anti-windup: freeze integral if we are saturating in the direction of the error.
        let headroom = (max_mag - min_mag).max(0.01);
        let saturated_high = u_tentative > headroom && error > 0.0;
        let saturated_low = u_tentative < -headroom && error < 0.0;
        if saturated_high || saturated_low {
            new_integral = self.integral;
        }
        self.integral = new_integral;
        let i_term = self.ki * self.integral;

        p_term + i_term + d_term + ff_term
    }
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

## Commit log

2026-03-21 More complex LED control
2026-03-23 Rename project to "DHD" and implement core functionality for volume control via potentiometer. Replace LED management with volume state management using a DI-based architecture. Update comments and l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
    [main.rs]
2026-03-23 Add median filtering and hysteresis to PotentiometerManager for smoother volume updates
2026-03-26 Add asynchronous PulseAudio support and JSON protocol documentation
    - Implement asynchronous system volume control via PulseAudio integration.
    - Refactor USB communication to utilize `tokio` for non-blocking operations.
    - Add `DHD Protocol Specification` documentation outlining JSON-based communication protocol.
    - Update dependencies to include `tokio`, `libpulse-binding`, `futures`, and related libraries.
    [main.rs]
2026-03-26 Add handshake mechanism to the DHD protocol for initial connection validation
    - Introduce a JSON-based handshake exchange between host and device.
    - Update host to send and validate handshake messages during connection initialization.
    - Modify firmware to respond to handshake challenges from the host.
    - Adjust ping interval to 1 second and implement a three-ping timeout mechanism for connection monitoring.
    - Update protocol documentation to include handshake and revised ping behavior.
2026-03-27 Implement PulseAudio caching for efficient volume operations
    - Add `PulseCache` struct to store default sink index, channel count, and refresh state.
    - Use subscription to detect default sink changes and update `PulseCache` accordingly.
    - Optimize volume setting by avoiding redundant introspection calls when cached data is valid.
    - Improve logging for default sink changes and apply thread safety with `Arc<Mutex>`.
    [main.rs]
2026-03-27 Add event-driven PulseAudio notifications and refine logging
    - Introduce `PulseEvent` enum for handling server and sink changes.
    - Implement `tokio::mpsc` channel to process PulseAudio events asynchronously.
    - Replace redundant introspection calls with targeted sink updates on event changes.
    - Consolidate and enhance logging with a reusable `log` helper function.
    - Refactor `PulseController` initialization to return an event receiver channel.
    [main.rs]
2026-03-28 WIP - Calibration - Finding boundaries
2026-03-28 WIP - Calibration - Low speed finding
2026-04-19 Calibration-driven clipping
2026-04-19 Internal PID controller lib
2026-04-20 PID controller real calibration
2026-04-20 Calibration of the physical PID
2026-04-21 Introduce physically and logically driven system modes
    This refactor addresses the need for robust, deterministic, and modular firmware operation without arbitrary delays. The main orchestrator is now split into distinct state handlers, including new `PhysicallyDriven` and `LogicallyDriven` modes synced to the host. PID loops are now driven natively at the 500Hz ADC rate, utilizing the new `was_driving` flag for convergence detection.
    Volume rounding to 1% precision is now applied directly after the filter in the fader task for stability, emitting updates unconditionally. In `PhysicallyDriven` mode, PID resistance is disabled to avoid resonance and rely on passive position reporting. Additi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
    [calibration.rs, controller.rs, main.rs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]
2026-04-21 [LOG-NONE] Implement persistent calibration storage and host-driven calibration
    This change adds support for storing fader calibration parameters in the RP2350
    flash memory, eliminating the need for a full calibration cycle on every boot.
    A dedicated 4KB .storage section has been carved out in the linker script,
    and a robust storage module with CRC-32 checksums and DMA-aligned buffering
    ensures data integrity.
    The calibration process is now host-driven. Upon connection, the host triggers
    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
2026-04-21 Refactor logging: host-side filtering and firmware verbosity cleanup
    This change moves detailed firmware diagnostic logs (calibration steps,
    flash operations, fader events) from info to debug/trace levels to keep
    the default output clean. The firmware now unconditionally sends all log
    messages to the host, shifting the responsibility of filtering to the
    host tool.
    The host tool has been updated with a new CLI interface using clap,
    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
2026-04-21 Add system tray icon and daemonization support
    The host program now supports a --systray flag which enables a system tray icon and detaches the process from the terminal. The tray icon provides real-time visualization of the device's FSM state us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
    - Added ksni and daemonize dependencies.
    - Implemented tray logic with custom state icons.
    - Added CLI support for daemonization.
    - Updated host logic to communicate state changes to the tray.
2026-04-21 Fix dynamic systray updates and enforce singleton daemon lock
    Bypass KDE's theme caching bug by returning absolute file paths to SVGs for the systray icon, enabling immediate visual state changes. The tray now tracks its own state and asynchronously pushes updates instantly.
    A robust file lock (~/.cache/dhd.lock) has been added to guarantee only a single host instance runs at a time. The lock is properly re-acquired post-daemonization to handle closed file descriptors.
    Additionally, the install subcommand output was rewritten to display a cleaner, color-coded directory tree of installed files.
    [main.rs]
2026-04-21 Update documentation to match current implementation
    Ensure the documentation accurately reflects the current state of the application. The protocol documentation now includes the `mode` and `update_calibration` messages. The wiring documentation has b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
2026-04-21 Embed SVG assets into binary and fix installation file busy error
    Assets are now compiled directly into the binary using the `include_bytes!` macro, eliminating the need for hardcoded development fallback paths and making the executable more self-contained. The installation process has also been updated to remove the target executable before copying if the canonical paths do not match, resolving an "OS Error 26 (Text file busy)" during reinstallation.
    [main.rs]
2026-04-25 Add KiCad project files and ignore build artifacts
    Add the initial KiCad project files. Update the .gitignore to exclude KiCad backups, autosaves, locks, and the derived gerbers/ directory to keep the repository clean.
    [dhd.kicad_pcb, dhd.kicad_sch]
2026-04-25 Submitted KiCad design v1
    [dhd.kicad_pcb, dhd.kicad_sch]
2026-05-06 Add scale inversion feature to flip volume direction
    Allow inverting the volume scale so that hardware 100% reads as
    volume 0% and vice-versa. This is useful for installations where the
    fader is mounted in reverse orientation.
    The inversion can be toggled from the host via SIGUSR2 or the systray
    "Invert Scale" menu item. The firmware persists the setting in flash
    alongside calibration data, reports it to the host during handshake,
    and applies it in real time to both ADC-to-volume conversion and
    incoming host volume commands.
    [calibration.rs, main.rs]
2026-05-10 Construction/assembly guide
    [dhd.kicad_pcb, dhd.kicad_sch]
2026-05-10 Adding STL files
    [DHD_Drawer.stl, DHD_Facade.stl, DHD_Knob.stl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]
2026-05-10 Reorganize documentation as a Zensical static site
    Replace the flat collection of markdown files with a structured
    documentation site built on Zensical (Material for MkDocs), managed as
    a uv Python project under doc/.
    Content changes:
    - Split construction.md into dedicated assembly section (BOM, PCB,
    3D printing, step-by-step, GEN2 drawer integration)
    - Add host software section (installation, usage, JSON protocol
    reference with mermaid sequence diagrams)
    - Add internals section (PID controller, DRV8833 motor driver, wiring)
    cross-checked against source code and KiCad schematics
    - Convert product photos from HEIC to JPG and strip EXIF metadata
    - Generate STL thumbnails via OpenSCAD au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
2026-05-10 Fix GitHub links to point to develop instead of master
    All documentation links (blob, tree, raw references) pointed to the
    master branch, which no longer exists. Updated every occurrence across
    the README and all doc pages so that STL downloads, KiCad schematics,
    firmware source links, and code references resolve correctly against
    the actual default branch, develop.
2026-05-10 Clarify Pico 2 compatibility expectations in BOM
    The previous note vaguely said "any Raspberry Pi Pico should do the job"
    while being "totally untested", which was misleading. Replace it with
    specific guidance:
    - Pico 2 (non-W) is the tested target
    - Pico 1 requires a firmware retarget due to the RP2040 vs RP2350 difference
    - Pico 2 W shares the same chip but is untested, with potential USB/power
    concerns from the wireless hardware
    This sets clearer expectations for anyone sourcing parts.
